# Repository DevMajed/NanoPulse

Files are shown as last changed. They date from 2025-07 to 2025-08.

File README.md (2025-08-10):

# NanoPulse – A Precision 24-bit Pulse Capture Digitizer
Hardware project — firmware will live in another repo.

# Purpose & Use Cases
**NanoPulse** is a 2-channel, 24-bit, trigger-synchronized digitizer for **µs-scale pulses**. It gives a cleaner, more deterministic “scope view” with higher vertical resolution, lower drift, and easy automation in a tiny form factor.
- What: 24-bit, 2-channel digitizer for µs pulses (hundreds of kHz BW).  
- For: labs validating pulse shape, battery DCIR, and rail transients, Ultrasonic/sonar echo logger (lab/test-tank, 40–300 kHz)
- Why: cleaner data than 8–12-bit scopes, deterministic trigger, tiny + scriptable.








---

# Purpose & Use Cases

**NanoPulse** delivers a deterministic external-trigger capture path tuned for **hundreds of kHz BW** and **µs pulses**.

## 1) Scope-replacement for pulsed benches (µs pulses)
**What it solves**  
Verify the **actual** applied pulse (rise/fall, overshoot, flatness, droop) without wheeling in a DSO.

**Who it’s for**  
Power-electronics / microwave labs, bench integrators.

**Hook**  
24-bit depth + clean CNV trigger reveals subtle flat-top errors and overshoot that 8–12-bit scopes smear.

**Connect (minimal extras)**
- `Sense Out (BNC/SMA)` → `NanoPulse IN` *(use a simple divider if needed)*
- `External Trigger (DDG/TTL)` → `TRIG IN` *(optional on-board 50 Ω)*

**Quick checklist**
- [ ] Minimal overshoot/ringing  
- [ ] Flat-top ripple/droop within spec  
- [ ] Repeated pulses overlay tightly (deterministic timing)

**Output**  
CSV + plots via simple Python scripts.

---

## 2) Battery / Cell DCIR & Pulsed-Load Logging
**What it solves**  
Clean capture of **voltage droop and relaxation** during programmed load pulses (≈10 µs–100 ms) for DCIR and transient analysis.

**Who it’s for**  
Battery research labs, EV startups, QA.

**Hook**  
High dynamic range + low drift → clearer droop and recovery curves than a typical scope; easy CSV export.

**Connect (minimal extras)**
- `Cell V` → `NanoPulse IN` *(add a 2-resistor divider if V exceeds input range)*  
- Optional: `Shunt V (current)` → `CH2`

**Quick checklist**
- [ ] Stable ΔV (droop) across repeats  
- [ ] Consistent relaxation time constants (τ)  
- [ ] Negligible baseline drift on long captures

**Output**  
CSV of V(t) (and I(t) if used), with auto-computed DCIR and τ.

---

## 3) Power-Rail / Load-Step Transient Verification (PMIC/LDO)
**What it solves**  
Measures **droop, settling time, and small ripple** on precision rails during load steps (≈100 µs–10 ms).

**Who it’s for**  
Analog/PMIC teams, embedded HW labs.

**Hook**  
24-bit vertical resolution + drift stability → see micro-ripple/settling that scopes miss.

**Connect (minimal extras)**
- `Rail` → `NanoPulse IN` *(use a small divider if needed)*  
- `Load-Step Trigger` → `TRIG IN` *(or use Manual Trigger)*

**Quick checklist**
- [ ] Droop within budget  
- [ ] No excessive undershoot/overshoot  
- [ ] Settling to ±x% within target time

**Output**  
CSV + auto-generated plot with annotated droop/settling metrics.

---

## 4) Ultrasonic / Sonar Echo Logging (lab/test-tank, 40–300 kHz)

**What it solves**  
Time-locked recording of **echo waveforms** for TOF, envelope, and multipath analysis—without touching OEM sonar firmware.

**Who it’s for**  
University acoustics/ultrasound labs, NDT benches, AUV/ROV research groups.

**Hook**  
24-bit dynamic range + deterministic trigger resolves **weak echoes** and small envelope changes better than typical 12–16-bit scopes.

**Connect (minimal extras)**
- `Receiver/Baseband Out (BNC/SMA)` → `NanoPulse IN` *(stay within input range or use a simple divider)*  
- `TX Sync/Trigger (TTL)` → `TRIG IN` *(optional on-board 50 Ω)*

**Quick checklist**
- [ ] Stable ping-to-echo timing (TOF) across repeats  
- [ ] Envelope + multipath clearly visible in the 40–300 kHz band  
- [ ] No clipping; baseline drift negligible on long logs

**Output**  
CSV of echo segments + optional envelope/spectrogram plots via Python.

---

# Headline Specs
- **ADC:** Analog Devices **AD4630-24**, up to **2 MSPS**, 24-bit  
- **Channels:** 2 differential, fully-differential amp (FDA) driven  
- **Trigger:** external **TRIG IN** → Schmitt-conditioned → CNV; **Manual Trigger** pad  
- **I/O domains:** **1.8 V** (ADC) and **3.3 V** (MCU) with level translators  
- **Reference:** **LTC6655-5** low-noise, low-drift  
- **Rails:** **LT3042** (+5.4 V), **LT3093** (−5.4 V), **LT1763** (1.8 V & 3.3 V)  
- **Configurable 50 Ω trigger termination** for DDG/coax use (DNP by default)

**Bandwidth envelope (typical build)**
- Usable analog BW: ~**300–600 kHz** (tunable via RCs)
- Practical “clean shape” pulse widths: **≥ 5–10 µs** (2 MSPS sampling)
- **Detect-only minimum pulse:** ~**1–2 µs** (1–2 samples)

---

# Design Highlights (Decisions & Rationale)
- **Anti-alias vs. settling (µs pulses in mind):** modest input Rs (~54 Ω) and small caps (≈1–2.7 nF) around the FDA target a **few-hundred-kHz to ~1 MHz** shaping—enough to see µs edges while improving settling and noise.
- **Low-drift reference path:** **LTC6655-5** with **10 µF + 0.1 µF** close to ADC REF minimizes baseline wander in long captures.
- **Trigger integrity:** External TRIG goes through a **Schmitt buffer + enable/OR logic** to produce a crisp **CNV**; **50 Ω** termination is **optional** for DDG/coax use.
- **Signal integrity at the converter:** **33 Ω series** per ADC input leg for damping; **22–33 Ω** on **CNV** after level translation to tame edges.
- **Clean domain split:** Translators isolate the quiet **1.8 V ADC** domain from **3.3 V MCU**, enabling fast SPI and **BUSY** handshaking.

---

## Trigger Modes
- **External-coax (DDG):** populate 50 Ω at TRIG IN; QC/DDG drives a matched line.  
- **Local-logic:** leave 50 Ω DNP; CNV is driven via translator with a **22–33 Ω** series resistor.

---

## Bring-Up Checklist
- **Power-only:** verify +5.4 V, −5.4 V, +3.3 V, +1.8 V rails; REF ≈ 5.000 V.  
- **CNV source:** confirm 3.3 V at Schmitt output and **1.8 V** at ADC CNV.  
- **Zero-volt short noise:** short IN+ to IN− at SMA; log RMS code spread.  
- **Step/edge:** feed a known step; confirm minimal ringing and proper settling.  
- **Drift:** shorted input, log ≥1 h; expect very low baseline drift.

---

## Safety & Limits
- Keep inputs **within safe range** (use passive dividers when needed).  
- Target content **≤ ~1 MHz** and **µs-scale** pulses.  
- For **ns edges/RF**, use a high-BW DSO/GHz digitizer.

---

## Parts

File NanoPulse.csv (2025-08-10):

Reference | Qty | Value | DNP | Exclude from BOM | Exclude from Board | Footprint | Manufacturer | Mfg part # | Digikey
C1,C3,C7,C8,C10,C17,C18,C19,C66,C67,C75,C76 | 12 | 1uF |  |  |  | Capacitor_SMD:C_0603_1608Metric | Samsung Electro-Mechanics | CL10B105KP8NNNC | 1276-1946-1-ND
C2,C4,C16 | 3 | 47uF 25V 1206 |  |  |  | Capacitor_SMD:C_1206_3216Metric | Cal-Chip Electronics, Inc. | GMC31X5R476M25NT | 4713-GMC31X5R476M25NTCT-ND
C5,C6,C14,C43,C44,C45,C46,C51,C52,C53,C54,C59,C60,C68,C69 | 15 | 0.01uF 0603 |  |  |  | Capacitor_SMD:C_0603_1608Metric | KEMET | C0603C103J5REC7411 | 399-17568-1-ND
C9,C41,C47,C48,C55,C56 | 6 | 10uF 25V 1206 |  |  |  | Capacitor_SMD:C_1206_3216Metric | Samsung Electro-Mechanics | CL31A106MAHNNNE | 1276-1181-1-ND
C11,C13 | 2 | 100uF |  |  |  | Capacitor_Tantalum_SMD:CP_EIA-3528-21_Kemet-B | KYOCERA AVX | TPSB107K006R0400 | 478-4976-1-ND - Cut Tape
C12,C15,C23,C26,C27 | 5 | 4.7uF |  |  |  | Capacitor_SMD:C_0805_2012Metric | Samsung Electro-Mechanics | CL21A475KAQNNNE | 1276-1244-1-ND
C20,C21 | 2 | 10uF 1206 |  |  |  | Capacitor_SMD:C_1206_3216Metric | Samsung Electro-Mechanics | CL31A106MAHNNNE | 1276-1181-1-ND
C22 | 1 | 0.47uF |  |  |  | Capacitor_SMD:C_0805_2012Metric | Samsung Electro-Mechanics | CL21B474KAFNNNG | 1276-6480-1-ND
C24 | 1 | 47uF 1206 |  |  |  | Capacitor_SMD:C_1206_3216Metric | Cal-Chip Electronics, Inc. | GMC31X5R476M25NT | 4713-GMC31X5R476M25NTCT-ND
C25,C28,C29,C30,C31,C32,C33,C34,C35,C36,C37,C38,C39,C40,C42,C61,C70,C77,C78,C79,C80,C81,C82,C83,C84,C85 | 26 | 0.1uF |  |  |  | Capacitor_SMD:C_0603_1608Metric | YAGEO | CC0603KRX7R7BB104 | 311-1088-1-ND
C49,C50,C57,C58,C64,C65,C73,C74 | 8 | 1000pF |  |  |  | Capacitor_SMD:C_0603_1608Metric | Samsung Electro-Mechanics | CL10B102KB8NNNC | 1276-1018-1-ND
C62,C63,C71,C72 | 4 | 2700pF |  |  |  | Capacitor_SMD:C_0805_2012Metric | Samsung Electro-Mechanics | CL21B272KBANNNC | 1276-2495-1-ND
D1,D2,D3,D4,D10 | 5 | ESD9B5.0ST5G |  |  |  | Diode_SMD:D_SOD-923 |  | ESD9B5.0ST5G | ESD9B5.0ST5GOSCT-ND - Cut Tape
D5,D6,D8,D9,D11,D12 | 6 | Green |  |  |  | LED_SMD:LED_0603_1608Metric | Lite-On Inc. | LTST-C191KGKT | 160-1446-1-ND
D7 | 1 | ESD9B3.3ST5G |  |  |  | Diode_SMD:D_SOD-923 |  | ESD9B3.3ST5G | ESD9B3.3ST5GOSCT-ND
D13 | 1 | LED_RGB |  |  |  | Majed-footprints:APHF1608SEEQBDZGKC_KNB-L | Kingbright | APHF1608SEEQBDZGKC | 754-2144-2-ND
FB1,FB2,FB3,FB4,FB5,FB6,FB7,FB8,FB9,FB10,FB11,FB12,FB13,FB14,FB15 | 15 | 33R |  |  |  | Inductor_SMD:L_0603_1608Metric_Pad1.05x0.95mm_HandSolder | Murata Electronics | BLM18PG330SN1D | 490-5220-1-ND
H1,H2,H3,H4 | 4 | NPTH_PAD |  | Excluded from BOM |  | Mounting_Wuerth:Mounting_Wuerth_WA-SMSI-M1.6_H3.5mm_ThreadDepth2mm_NoNPTH_97730356330
J1,J2,J3,J4,J5 | 5 | SMA_conn |  |  |  | Connector_Coaxial:SMA_Amphenol_132289_EdgeMount | Amphenol RF | 132289RP | ACX1427-ND
J6 | 1 | Conn_01x03_Pin |  |  |  | Connector_Phoenix_MC:PhoenixContact_MC_1,5_3-G-3.5_1x03_P3.50mm_Horizontal | Sullins Connector Solutions | PRPC003SAAN-RC | S1011EC-03-ND
J7 | 1 | STM32 PROGRAMER |  |  |  | Majed-footprints:SPARKFUN_PRT-14417 | SparkFun Electronics | 14417 | 1568-14417-ND
J8 | 1 | USB_B_Micro |  |  |  | Connector_USB:USB_Micro-B_Molex-105017-0001 | Molex | 0473461001 | WM11228CT-ND
Logo1 | 1 | Majed's Logo |  | Excluded from BOM |  | Majed-footprints:Logo_Majed | N-Well Labs
Q1 | 1 | 2N7002K |  |  |  | Package_TO_SOT_SMD:SOT-23 | onsemi | 2N7002LT1G | 2N7002LT1GOSCT-ND
R1,R2,R7,R8 | 4 | 50 |  |  |  | Resistor_SMD:R_0603_1608Metric | YAGEO | RT0603BRE0750RL | 13-RT0603BRE0750RLCT-ND
R3,R4,R5,R6,R35,R44,R45,R54,R55,R56,R57,R66,R67 | 13 | DNI |  |  |  | Resistor_SMD:R_0603_1608Metric
R9,R18,R21,R22 | 4 | 330R |  |  |  | Resistor_SMD:R_0603_1608Metric | TE Connectivity Passive Product | CRGP0603F330R | A130410CT-ND
R10 | 1 | 140R |  |  |  | Resistor_SMD:R_0603_1608Metric | Panasonic Electronic Components | ERJ-3EKF1400V | P140HCT-ND
R11 | 1 | 47.5K |  |  |  | Resistor_SMD:R_0603_1608Metric | YAGEO | RC0603FR-071KL | 311-47.5KHRCT-ND
R12,R14,R15,R26,R29,R30,R31,R32,R46,R48,R58,R60 | 12 | 10K |  |  |  | Resistor_SMD:R_0603_1608Metric | YAGEO | RC0603FR-0710KL | 311-10.0KHRCT-ND
R13 | 1 | 16.9K |  |  |  | Resistor_SMD:R_0603_1608Metric | Stackpole Electronics Inc | RMCF0603FT16K9 | RMCF0603FT16K9CT-ND
R16 | 1 | 54.2K |  |  |  | Resistor_SMD:R_0603_1608Metric | KOA Speer Electronics, Inc. | RN73H1JTTD5422B25 | 2019-RN73H1JTTD5422B25CT-ND
R17 | 1 | 3.3K |  |  |  | Resistor_SMD:R_0603_1608Metric | YAGEO | RC0603FR-073K3L | 311-3.30KHRCT-ND
R19 | 1 | 54.9R |  |  |  | Resistor_SMD:R_0603_1608Metric | YAGEO | RC0603FR-0754R9L | 311-54.9HRCT-ND
R20 | 1 | 49.9K |  |  |  | Resistor_SMD:R_0603_1608Metric | YAGEO | RC0603FR-0756KL | 311-56KHRCT-ND
R23,R24 | 2 | 400 |  |  |  | Resistor_SMD:R_0603_1608Metric | Vishay Dale Thin Film | PAT0603E4000BST1 | PAT400ACT-ND
R25 | 1 | 825 |  |  |  | Resistor_SMD:R_0603_1608Metric | YAGEO | RC0603FR-07825RL | 311-825HRCT-ND
R27 | 1 | 100 |  |  |  | Resistor_SMD:R_0603_1608Metric | RC0603FR-07100RL | RC0603FR-07100RL | 311-100HRCT-ND
R28 | 1 | 20K |  |  |  | Resistor_SMD:R_0603_1608Metric | YAGEO | RC0603FR-0720KL | 311-20.0KHRCT-ND
R33 | 1 | 100K |  |  |  | Resistor_SMD:R_0603_1608Metric | YAGEO | RC0603FR-07100KL | 311-100KHRCT-ND
R34 | 1 | 0 |  |  |  | Resistor_SMD:R_0603_1608Metric | YAGEO | RC0603JR-070RL | 311-0.0GRCT-ND
R36,R37,R40,R41 | 4 | 10 |  |  |  | Resistor_SMD:R_0805_2012Metric | YAGEO | RC0805FR-0710RL | 311-10.0CRCT-ND
R38,R39,R42,R43,R68,R69,R70 | 7 | 33 |  |  |  | Resistor_SMD:R_0603_1608Metric | YAGEO | RC0603FR-072KL | 311-33GRCT-ND
R47,R49,R59,R61 | 4 | 54.09 |  |  |  | Resistor_SMD:R_0603_1608Metric | YAGEO | RC0603FR-0754R9L | 311-54.9HRCT-ND
R50,R51,R62,R63 | 4 | 1K |  |  |  | Resistor_SMD:R_0603_1608Metric | YAGEO | RC0603FR-071KL | 311-1.00KHRCT-ND
R52,R53,R64,R65 | 4 | 2K |  |  |  | Resistor_SMD:R_0603_1608Metric | YAGEO | RC0603FR-071KL | 311-2.00KHRCT-ND
R71 | 1 | 50 (1210) |  |  |  | Resistor_SMD:R_1210_3225Metric_Pad1.30x2.65mm_HandSolder | Vishay Dale | RCP1206W50R0JTP | 541-RCP1206W50R0JTPCT-ND
R72 | 1 | 500 |  |  |  | Resistor_SMD:R_0603_1608Metric | YAGEO | RT0603BRC07500RL | 13-RT0603BRC07500RLCT-ND
SW1 | 1 | Push - BOOT |  |  |  | Button_Switch_SMD:SW_Tactile_SPST_NO_Straight_CK_PTS636Sx25SMTRLFS | E-Switch | TL59NF160Q | EG2532CT-ND
TP1 | 1 | 5.4V |  |  |  | TestPoint:TestPoint_Pad_1.0x1.0mm
TP2 | 1 | 3.3V |  |  |  | TestPoint:TestPoint_Pad_1.0x1.0mm
TP3 | 1 | -5.4 |  |  |  | TestPoint:TestPoint_Pad_1.0x1.0mm
TP4 | 1 | 1,,8V |  |  |  | TestPoint:TestPoint_Pad_1.0x1.0mm
TP5,TP6 | 2 | 5V |  |  |  | TestPoint:TestPoint_Pad_1.0x1.0mm
TP7 | 1 | UART4_RX |  |  |  | TestPoint:TestPoint_Pad_1.0x1.0mm
TP8 | 1 | UART4_TX |  |  |  | TestPoint:TestPoint_Pad_1.0x1.0mm
TP9 | 1 | UART4_CTS |  |  |  | TestPoint:TestPoint_Pad_1.0x1.0mm
TP10 | 1 | GND |  |  |  | TestPoint:TestPoint_Pad_1.0x1.0mm
TP11 | 1 | SCK |  |  |  | TestPoint:TestPoint_Pad_1.0x1.0mm
TP12 | 1 | BUSY |  |  |  | TestPoint:TestPoint_Pad_1.0x1.0mm
TP13 | 1 | MOSI |  |  |  | TestPoint:TestPoint_Pad_1.0x1.0mm
TP14 | 1 | CNV |  |  |  | TestPoint:TestPoint_Pad_1.0x1.0mm
TP15 | 1 | /CS |  |  |  | TestPoint:TestPoint_Pad_1.0x1.0mm
TP16 | 1 | REF |  |  |  | TestPoint:TestPoint_Pad_1.0x1.0mm
TP17 | 1 | Trig_Detect |  |  |  | TestPoint:TestPoint_Pad_1.0x1.0mm
TP18 | 1 | Trig_Enable |  |  |  | TestPoint:TestPoint_Pad_1.0x1.0mm
TP19 | 1 | Manual_Trigger |  |  |  | TestPoint:TestPoint_Pad_1.0x1.0mm
U1,U2 | 2 | LT1763CS8#PBF |  |  |  | Majed-footprints:SO-8_S_LIT-L | Analog Devices Inc. | LT1763CS8#PBF | 505-LT1763CS8#PBF-ND
U3 | 1 | LT3093IDD-PBF |  |  |  | Majed-footprints:05-08-1725_ADI | Analog Devices Inc. | LT3093IDD#PBF | 505-LT3093IDD#PBF-ND
U4 | 1 | LT1763CS8-1.8-TRPBF |  |  |  | Majed-footprints:SO-8_S_LIT | Analog Devices Inc. | LT1763CS8-1.8#TRPBF | 505-LT1763CS8-1.8#TRPBFCT-ND
U5 | 1 | LTC6655LNBHMS8-5#PBF |  |  |  | Majed-footprints:MSOP-8_MS_LIT-L | Analog Devices Inc. | LTC6655LNBHMS8-5#PBF | 505-LTC6655LNBHMS8-5#PBF-ND
U6 | 1 | LT3042IDD-PBF |  |  |  | Majed-footprints:DFN-10_DD_LIT | Analog Devices Inc. | LT3042IDD#TRPBF | LT3042IDD#TRPBFCT-ND
U7 | 1 | STM32H730VBT6 |  |  |  | Package_QFP:LQFP-100_14x14mm_P0.5mm | STMicroelectronics | STM32H730VBT6 | 497-STM32H730VBT6-ND
U8 | 1 | ESDA6V1BC6 |  |  |  | Package_TO_SOT_SMD:SOT-23-6 | ESDA6V1BC6 | STMicroelectronics | 497-6635-1-ND
U9 | 1 | ECS-1612MV-120-CN-TR |  |  |  | Majed-footprints:ECS-1612MV-120-CN-TR | ECS Inc. | ECS-1612MV-120-CN-TR | XC2833CT-ND
U10 | 1 | AD4630-24 |  |  |  | Majed-footprints:05-08-1797_ADI-L | Analog Devices Inc. | AD4630-24BBCZ-RL | 505-AD4630-24BBCZ-RLCT-ND
U11,U12 | 2 | ADA4896-2ARMZ |  |  |  | Majed-footprints:RM_8_ADI | Analog Devices Inc. | ADA4896-2ARMZ | 505-ADA4896-2ARMZ-ND
U13,U14 | 2 | ADA4945 |  |  |  | Majed-footprints:LFCSP16_ADA4945-1ACPZ-R2_ADI-L | Analog Devices Inc. | ADA4945-1ACPZ-RL | 05-ADA4945-1ACPZ-RLCT-ND
U15,U17 | 2 | FXLH42245MPX |  |  |  | Majed-footprints:MLP24_4P5X3P5_ONS | onsemi | FXLH42245MPX | FXLH42245MPXCT-ND
U16 | 1 | FXL2T245L10X |  |  |  | Majed-footprints:MICROPAK10_2P1X1P6_ONS-L | onsemi | FXL2T245L10X | FXL2T245L10XCT-ND
U18 | 1 | 74LVC2G17GW,125 |  |  |  | Package_TO_SOT_SMD:SOT-363_SC-70-6 | Nexperia USA Inc. | 74LVC2G17GW,125 | 1727-4218-1-ND
U19 | 1 | 74AHC1G08GW,125 |  |  |  | Package_TO_SOT_SMD:SOT-353_SC-70-5 | Nexperia USA Inc. | 74AHC1G08GW,125 | 1727-3148-1-ND
U20 | 1 | 74AHC1G32GW,125 |  |  |  | Package_TO_SOT_SMD:SOT-353_SC-70-5 | Nexperia USA Inc. | 74AHC1G32GW,125 | 1727-3150-1-ND

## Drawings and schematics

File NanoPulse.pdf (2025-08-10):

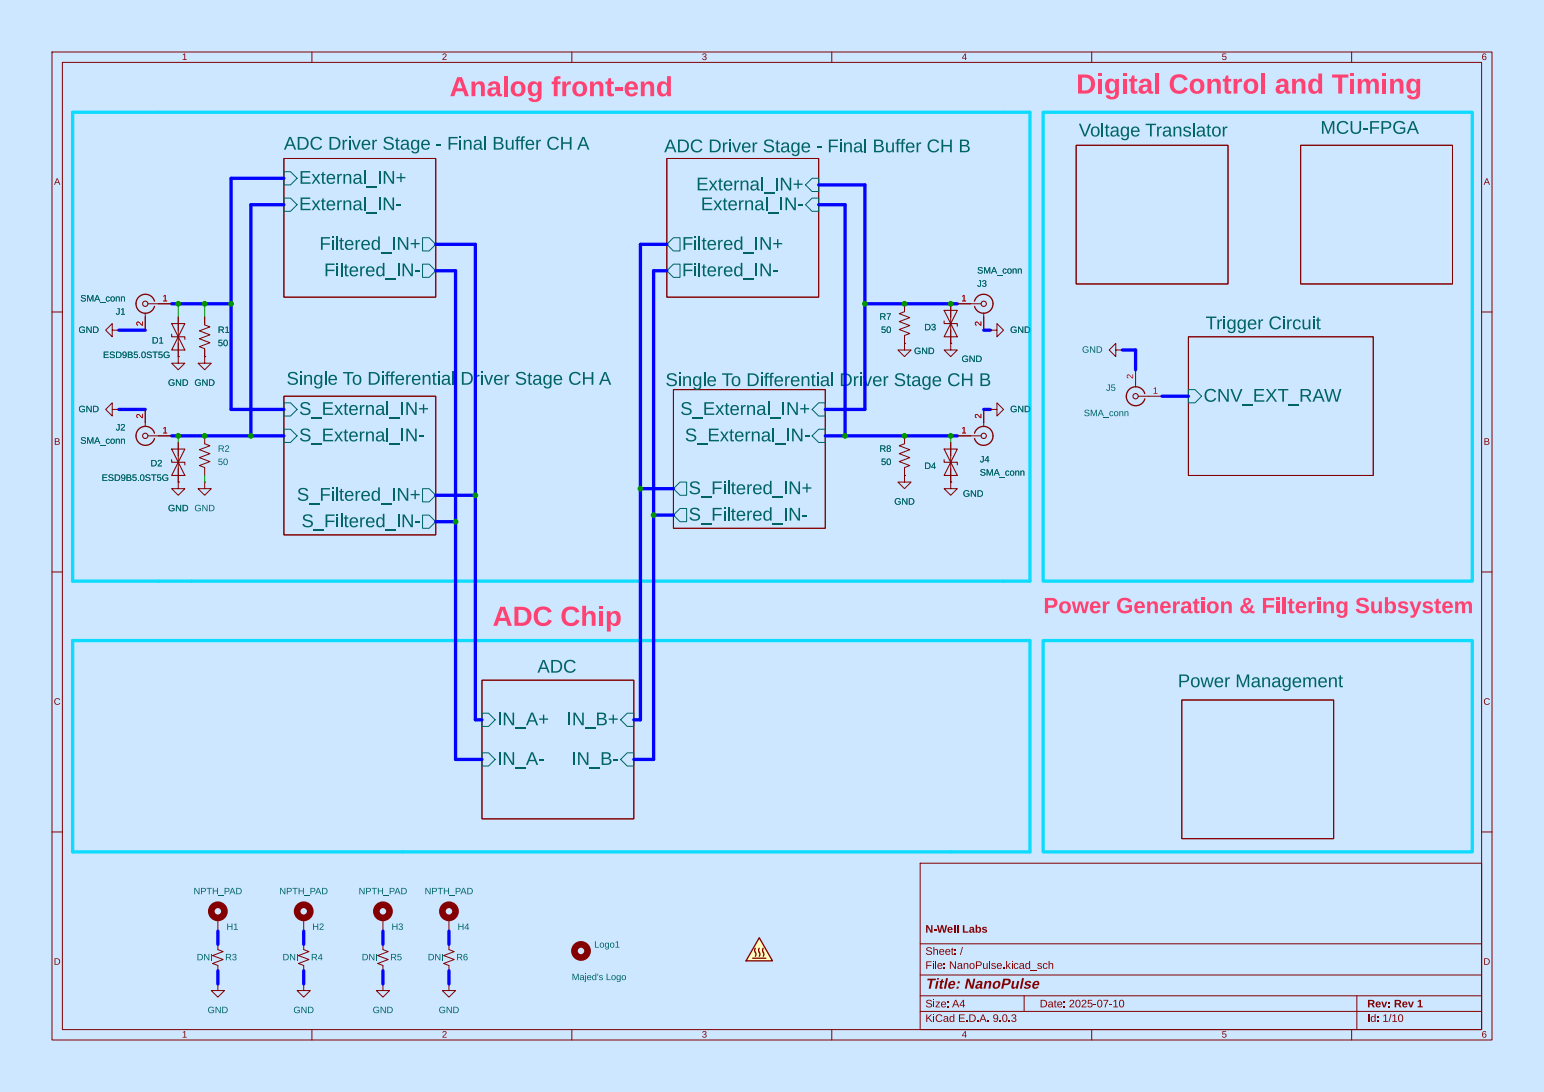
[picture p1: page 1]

Digital Control and Timing

ADC Driver Stage - Final Buffer CH A

ADC Driver Stage - Final Buffer CH B

Single To Differential Driver Stage CH A
S_External_IN+
S_External_IN-

Single To Differential Driver Stage CH B

Power Generation & Filtering Subsystem

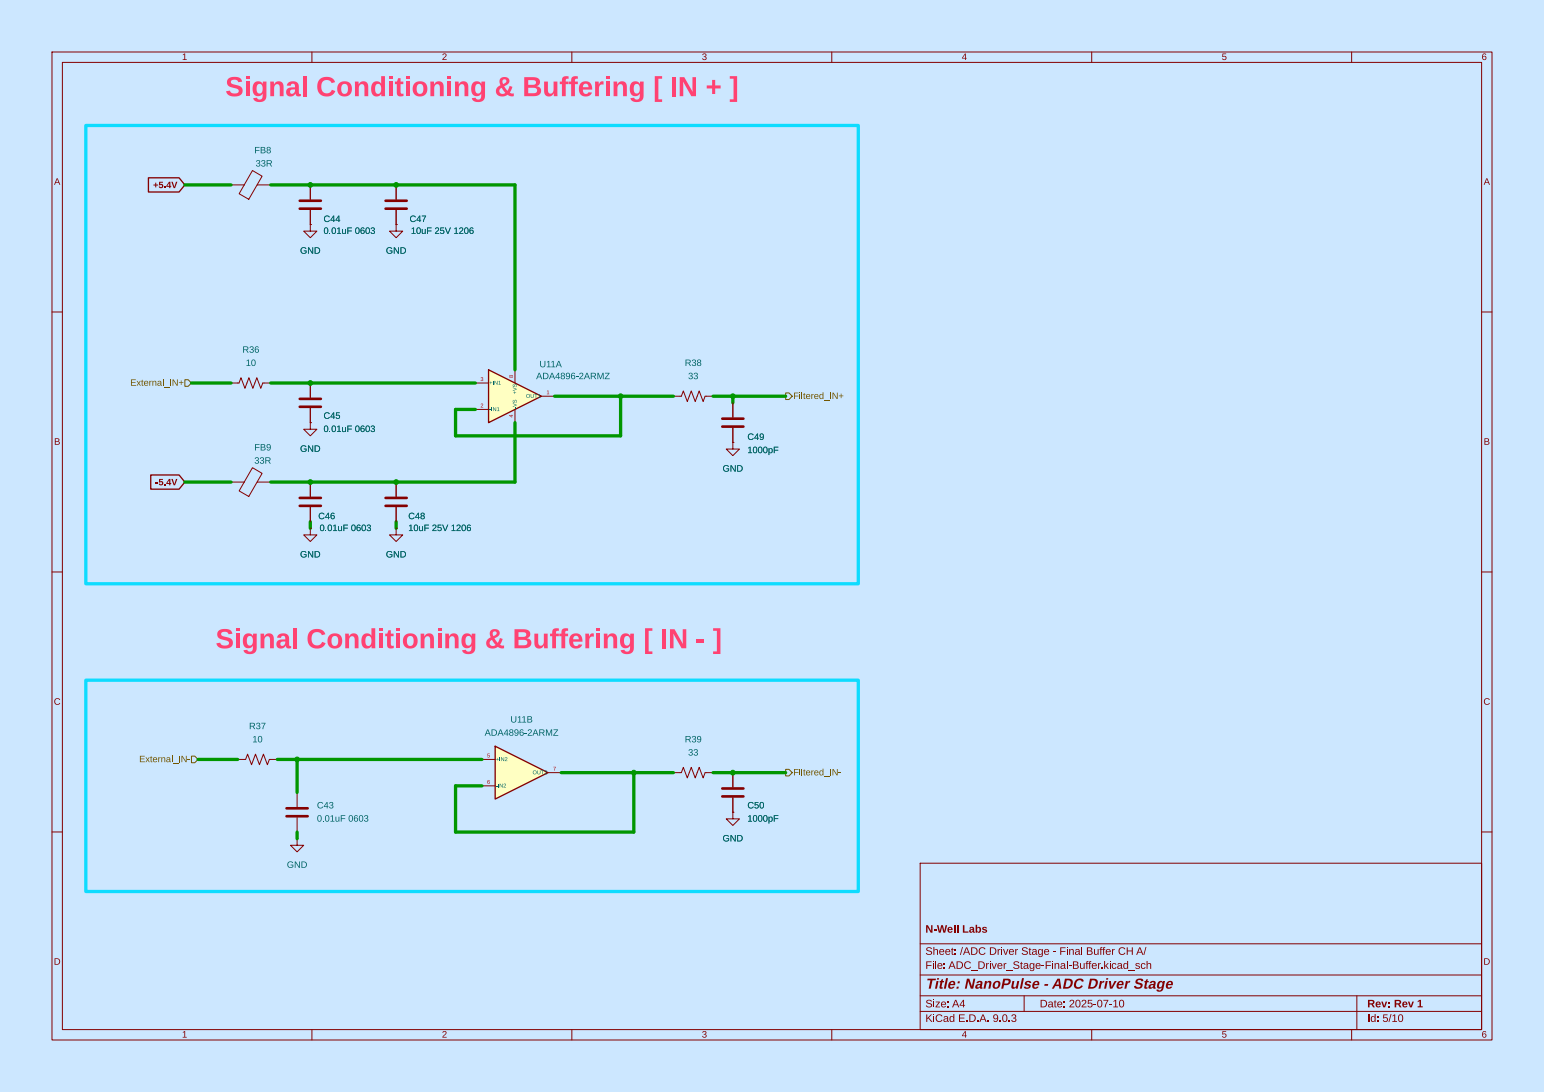
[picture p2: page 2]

Signal Conditioning & Buffering [ IN + ]

File: ADC_Driver_Stage-Final-Buffer.kicad_sch Sheet: /ADC Driver Stage - Final Buffer CH A/ N-Well Labs

Id: 5/10 Title: NanoPulse - ADC Driver Stage

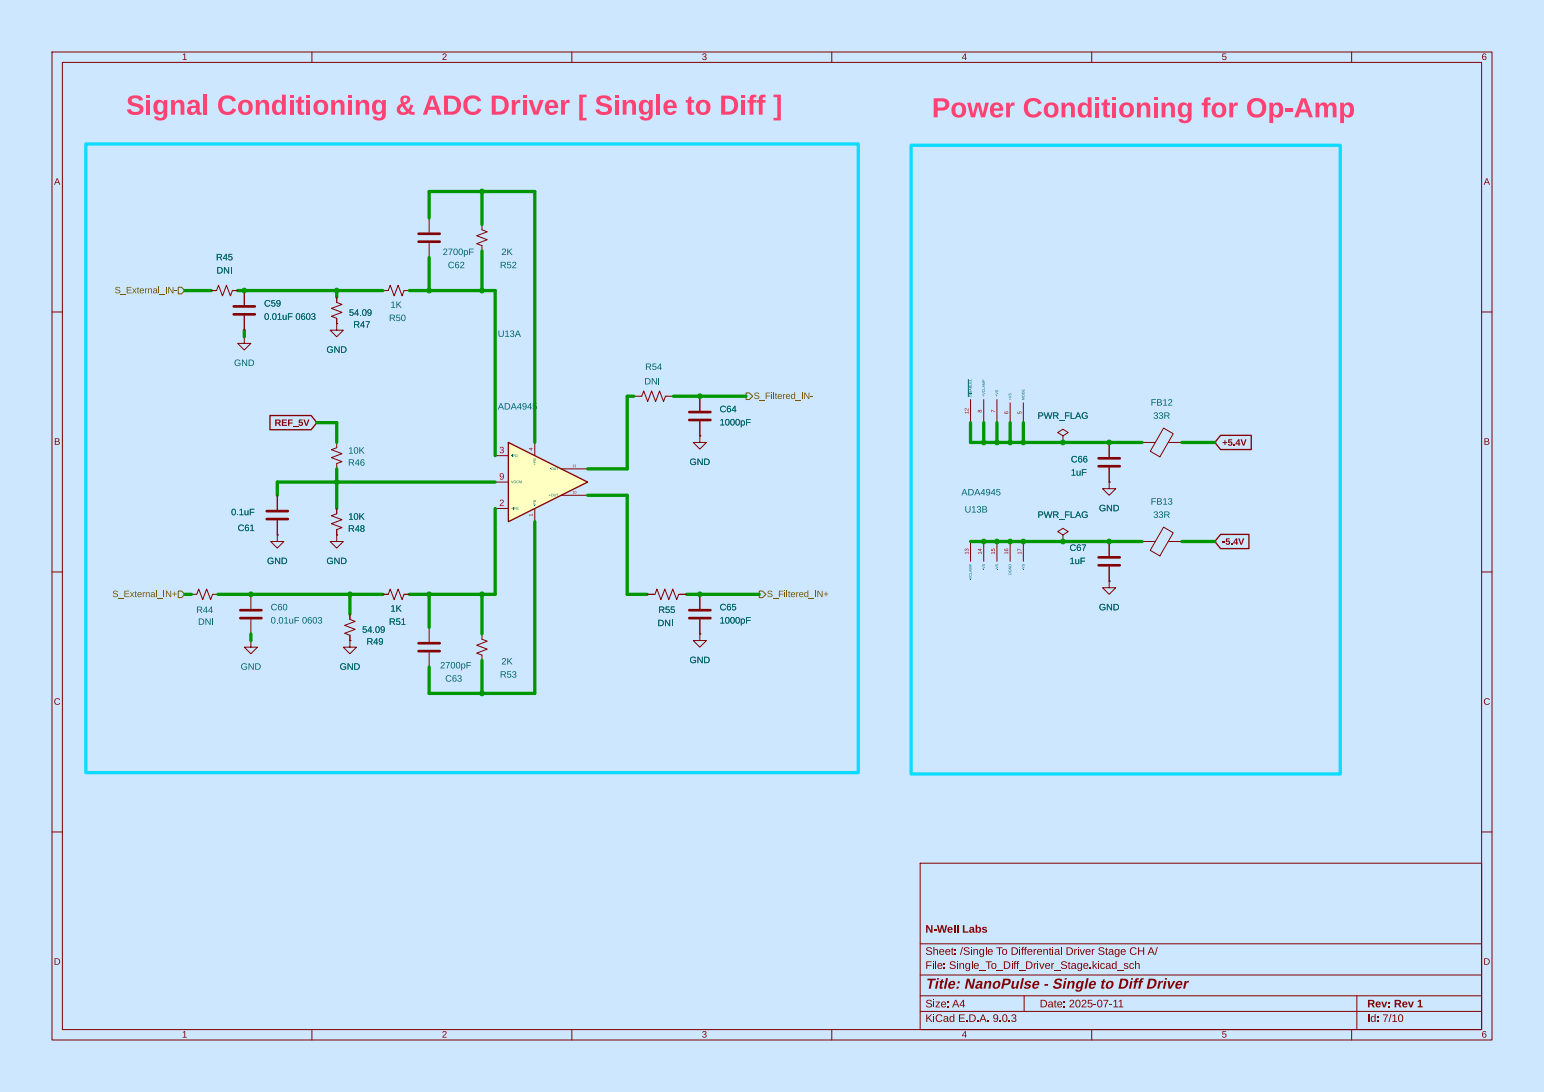
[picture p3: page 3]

Id: 7/10 Title: NanoPulse - Single to Diff Driver File: Single_To_Diff_Driver_Stage.kicad_sch Sheet: /Single To Differential Driver Stage CH A/ N-Well Labs

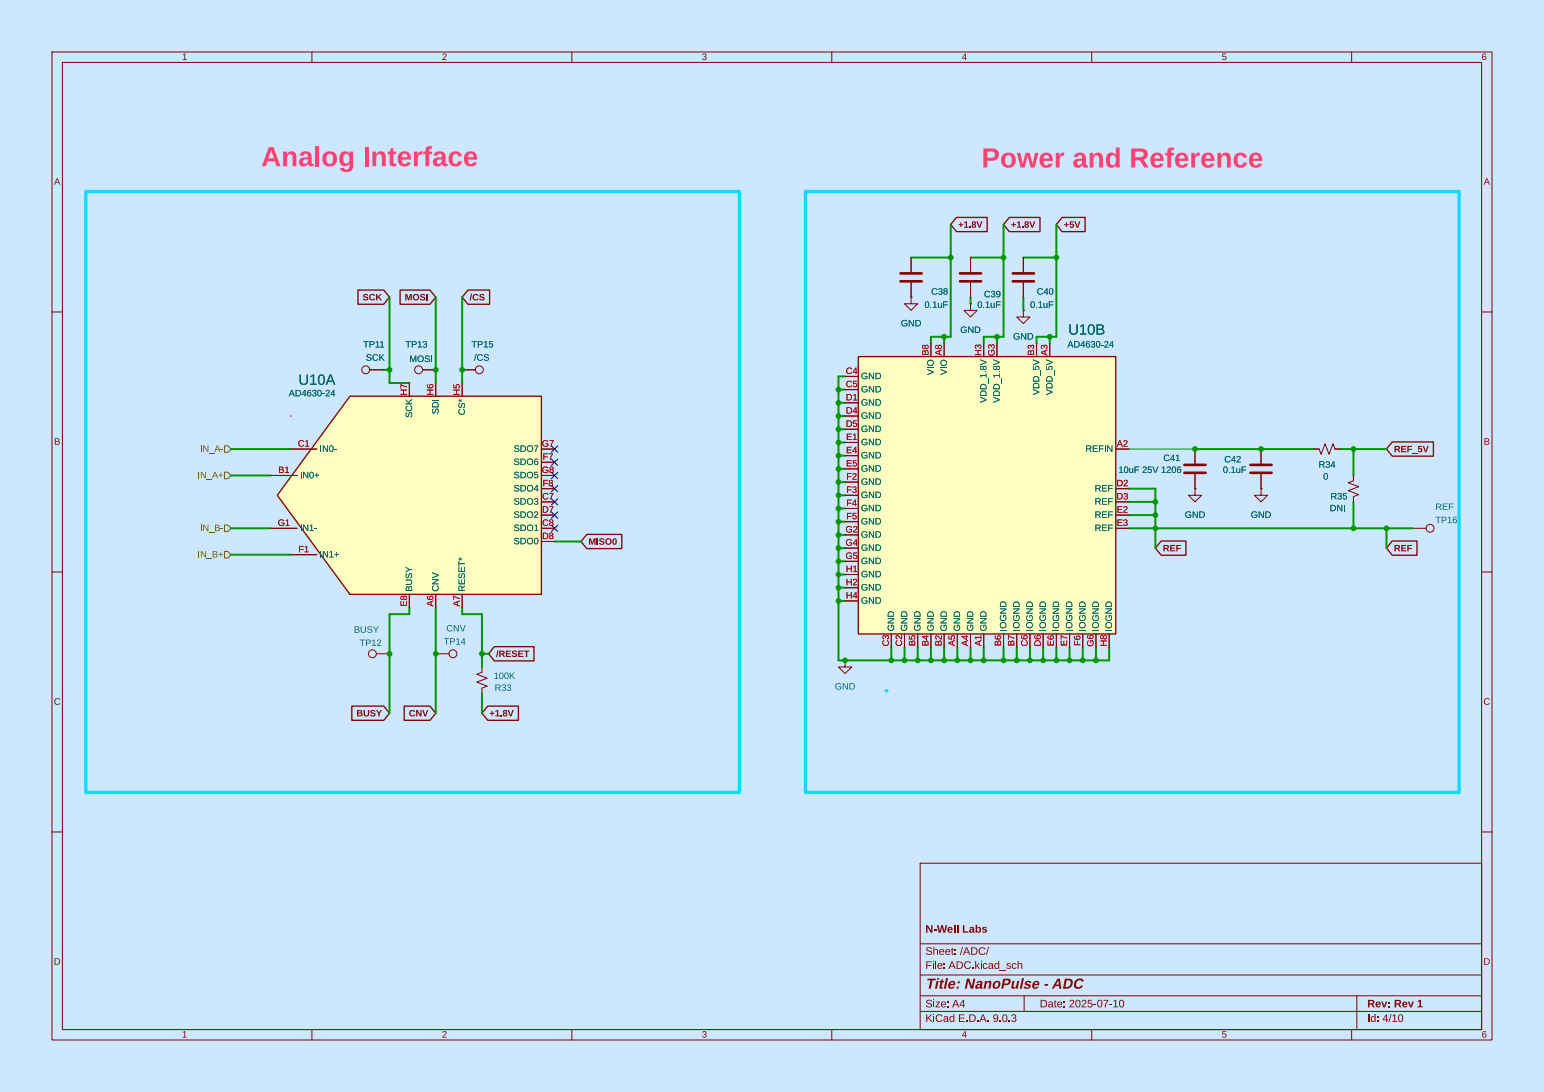
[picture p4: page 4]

SDO7 G7 SDO6 F7 SDO5 G8 SDO4 F8 SDO3 C7 SDO2 D7 SDO1 C8 SDO0 D8 CS* H5 RESET* A7 SDI H6 CNV A6 SCK H7 BUSY E8

File: ADC.kicad_sch Sheet: /ADC/ N-Well Labs

Id: 4/10 Title: NanoPulse - ADC

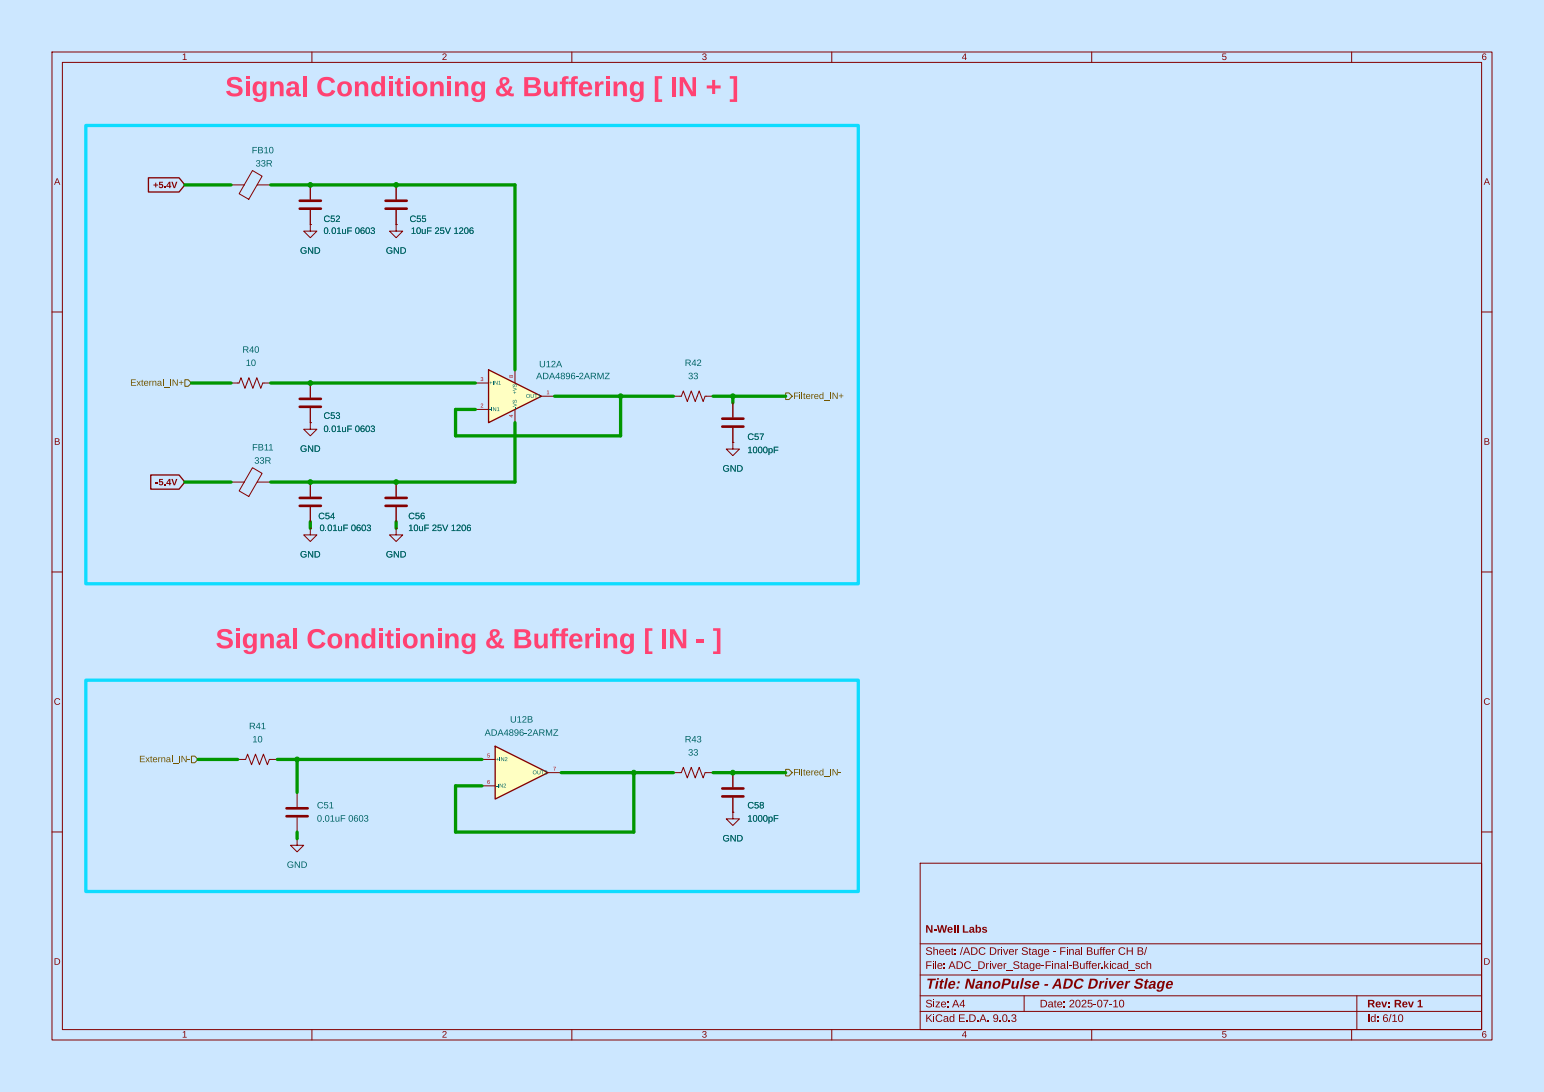
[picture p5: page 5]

Signal Conditioning & Buffering [ IN + ]

File: ADC_Driver_Stage-Final-Buffer.kicad_sch Sheet: /ADC Driver Stage - Final Buffer CH B/ N-Well Labs

Id: 6/10 Title: NanoPulse - ADC Driver Stage

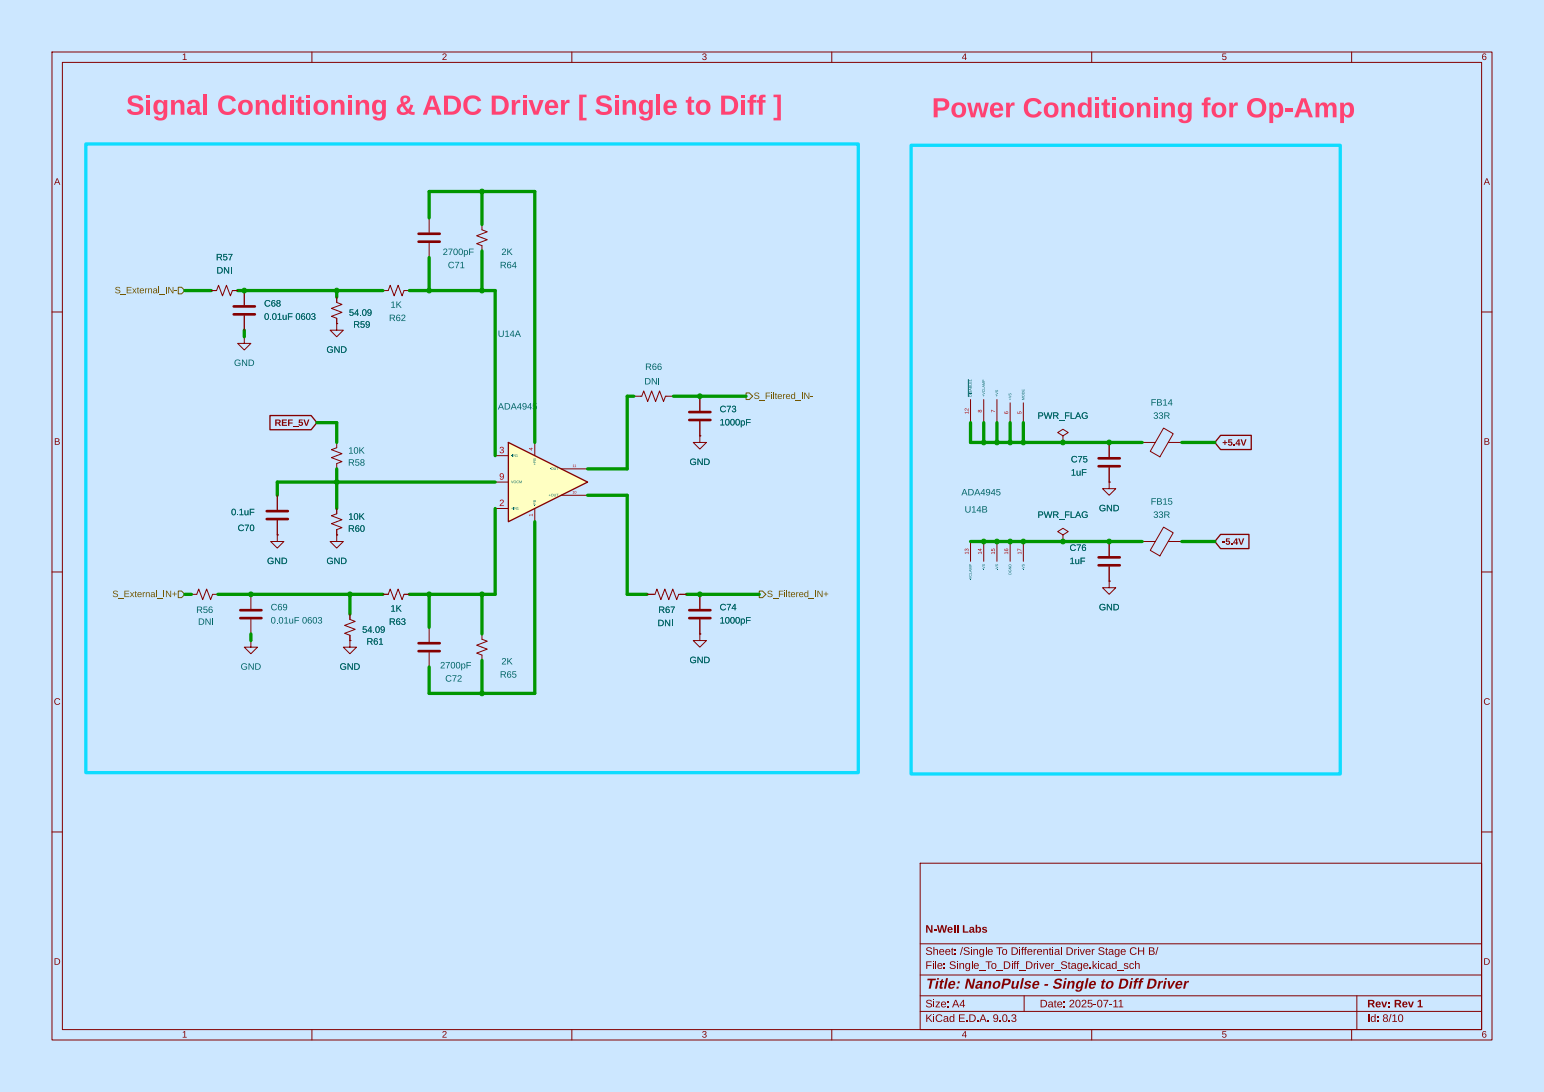
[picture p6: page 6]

1uF -VS 17 MODE 5 DGND 16 +VS 6 -VS 15 +VS 7 -VS 14 +VCLAMP 8 -VCLAMP 13 ~{DISABLE1} 12 U14B
33R GND

Id: 8/10 Title: NanoPulse - Single to Diff Driver File: Single_To_Diff_Driver_Stage.kicad_sch Sheet: /Single To Differential Driver Stage CH B/ N-Well Labs

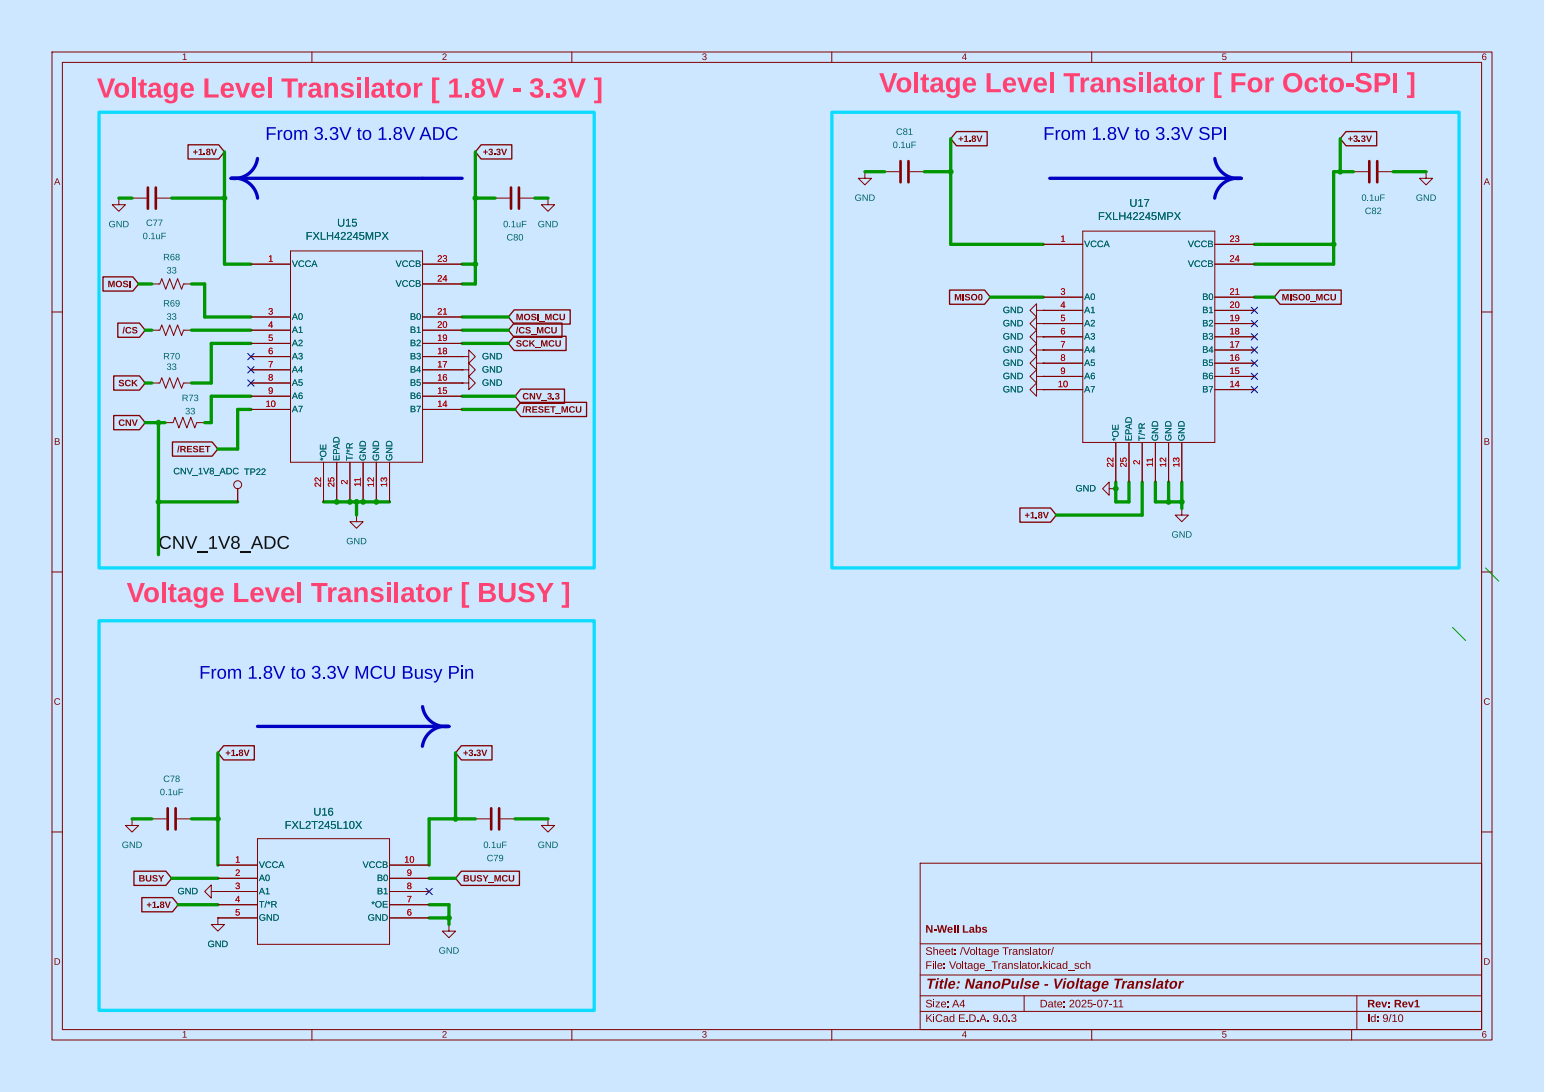
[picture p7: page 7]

2 GND 11 GND 12 GND 13 GND GND GND GND GND GND GND GND GND U15 FXLH42245MPX

Voltage Level Transilator [ BUSY ]

From 1.8V to 3.3V MCU Busy Pin

Id: 9/10 Title: NanoPulse - Violtage Translator File: Voltage_Translator.kicad_sch Sheet: /Voltage Translator/ N-Well Labs

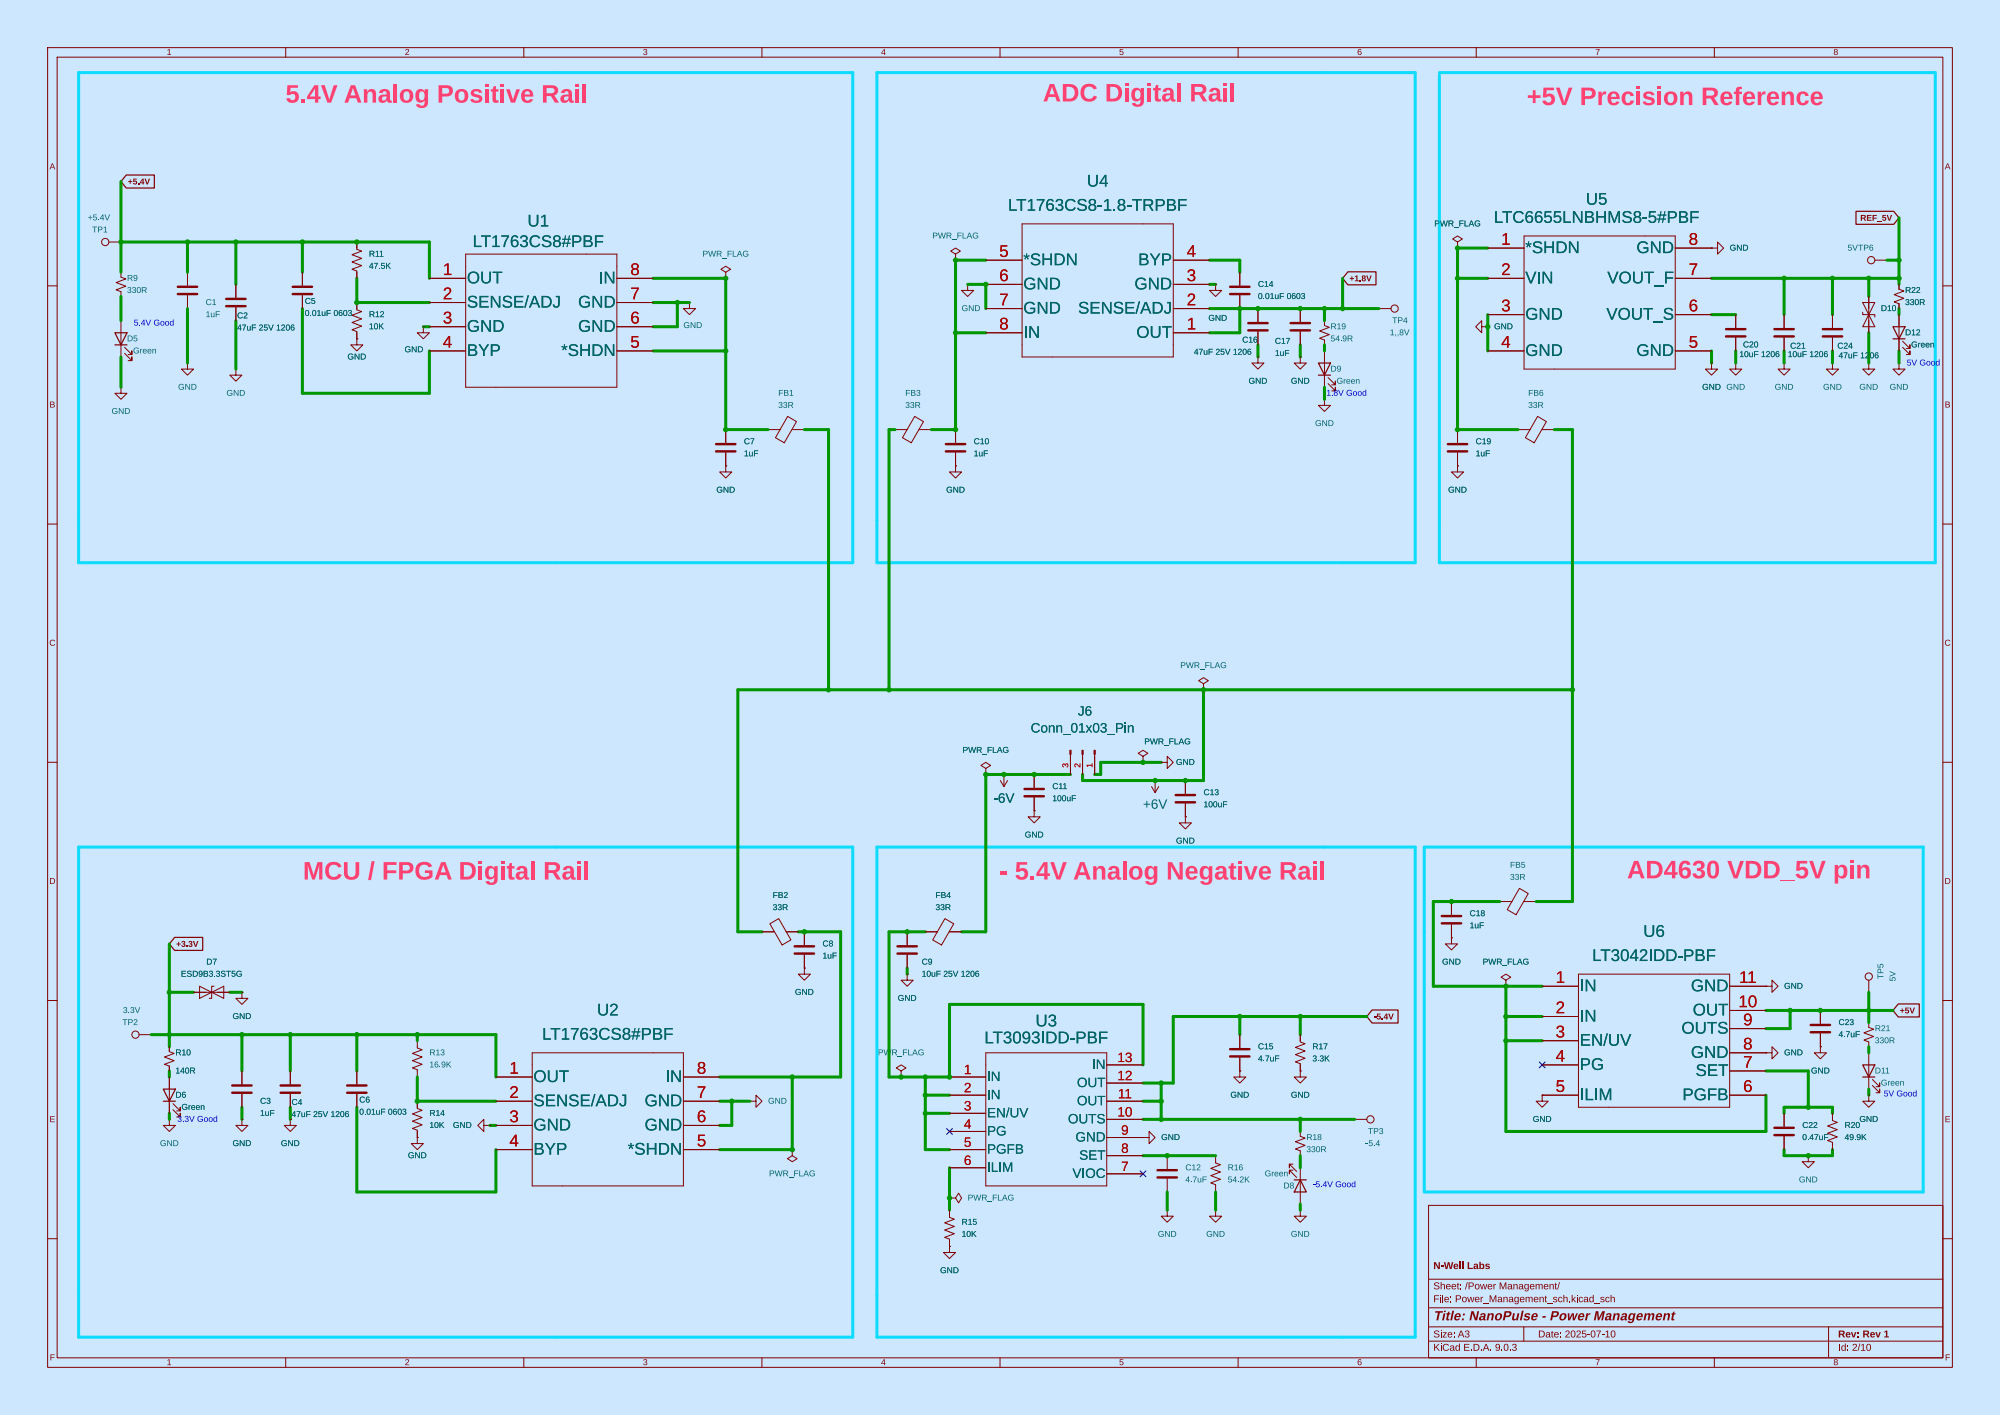
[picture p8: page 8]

5V Good 5.4V Analog Positive Rail

5V Good ADC Digital Rail

MCU / FPGA Digital Rail

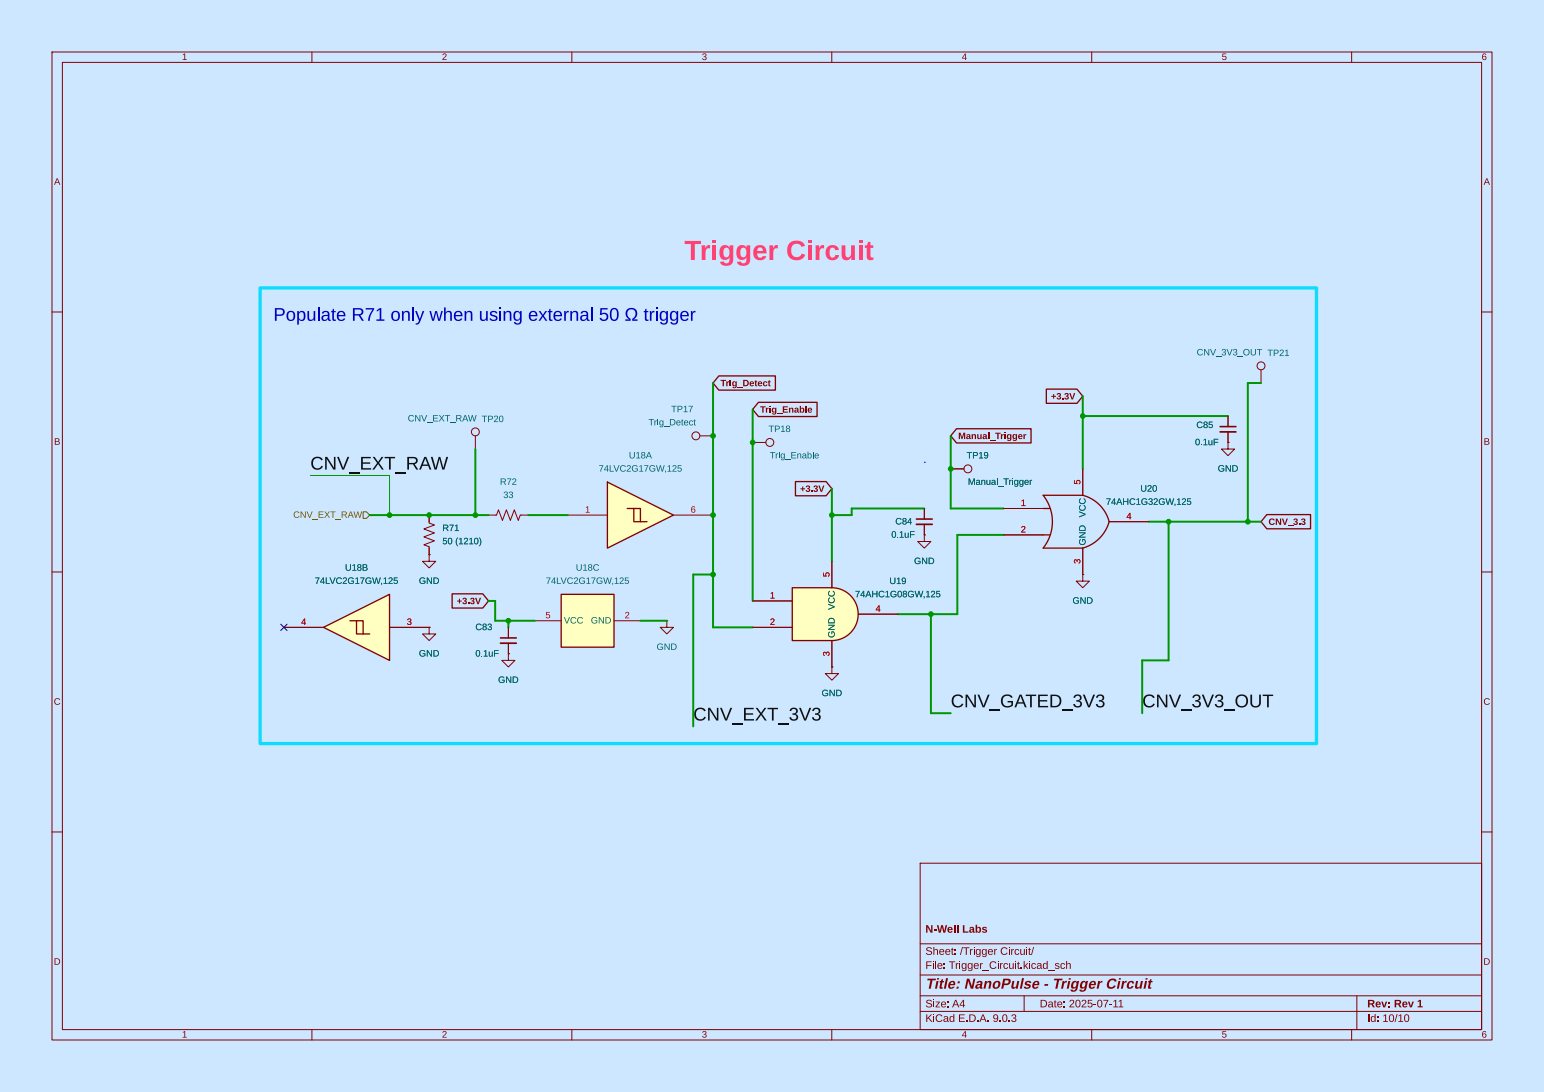
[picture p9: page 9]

Populate R71 only when using external 50 þÿ©trigger R71

Id: 10/10 Title: NanoPulse - Trigger Circuit File: Trigger_Circuit.kicad_sch Sheet: /Trigger Circuit/ N-Well Labs R71
50 (1210) GND

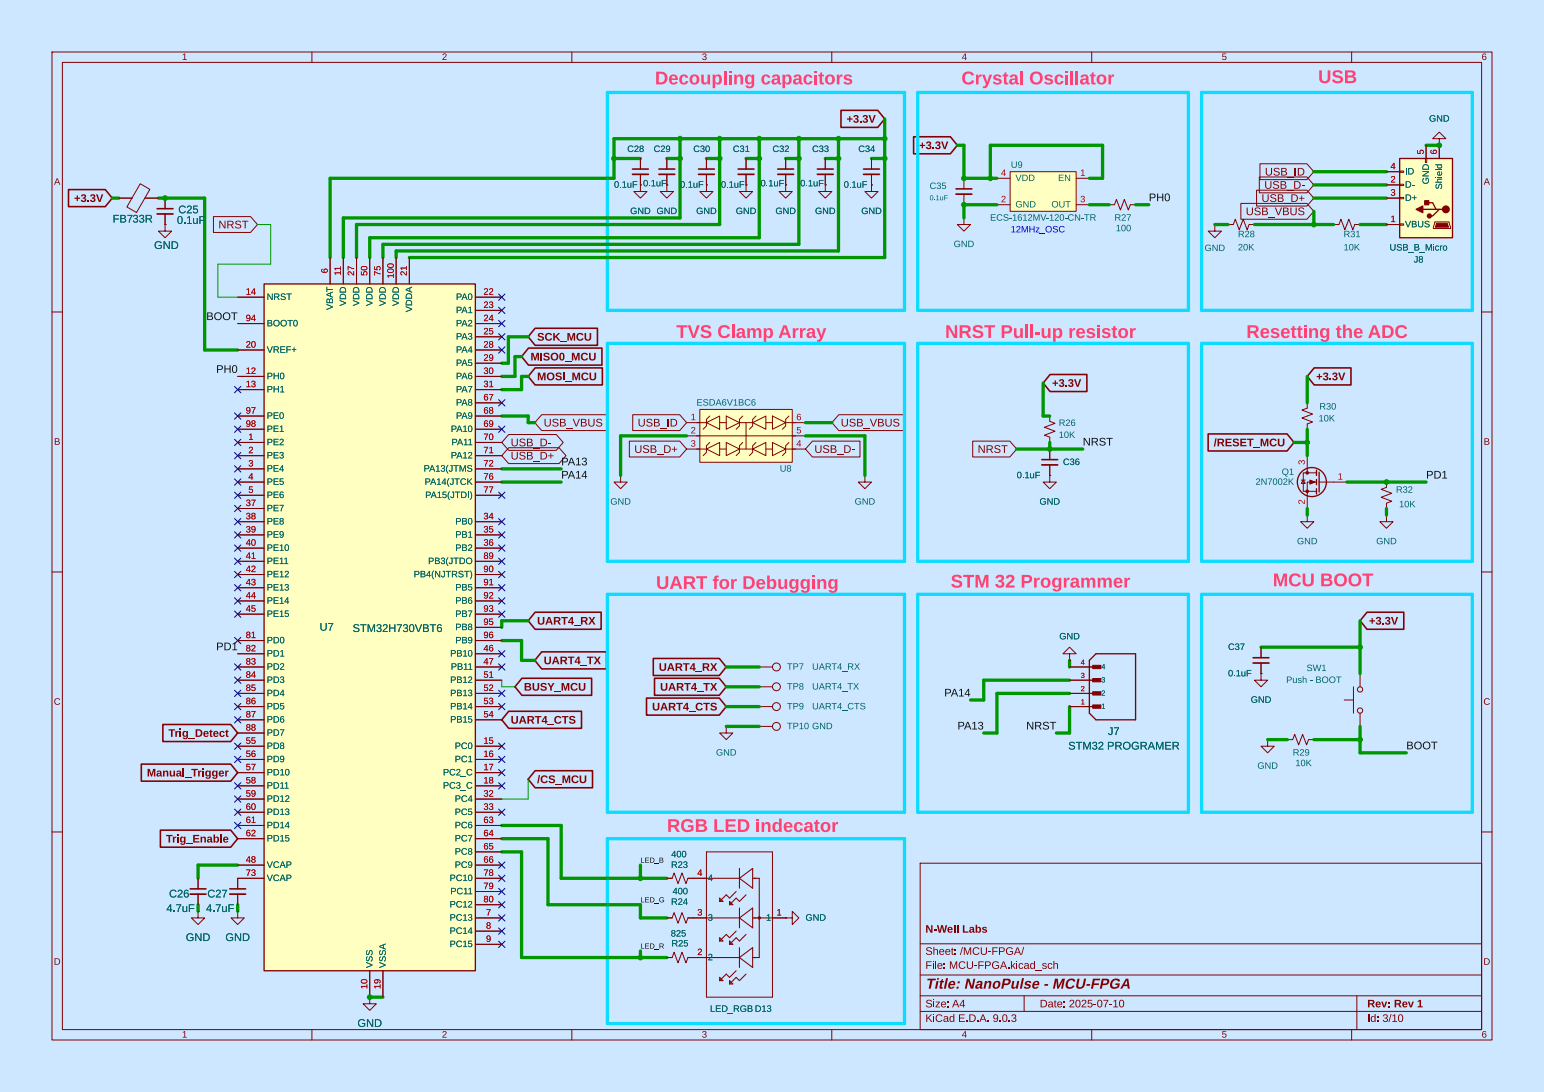
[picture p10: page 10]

6 VDD 11 VDD 27 VDD 50 VSS 10 VDD 75 VSSA 19 VDD 100 VDDA 21 PA0 22 PA1 23 PA2 24 PA3 25 PA4 28 PA5 29 PA6 30 PA7 31 PA8 67 PA9 68 PA10 69 PA11 70 PA12 71 PA13(JTMS 72 PA14(JTCK 76 PA15(JTDI) 77 PB0 34 PB1 35 PB2 36 PB3(JTDO 89 PB4(NJTRST) 90 PB5 91 PB6 92 PB7 93 PB8 95 PB9 96 PB10 46 PB11 47 PB12 51 PB13 52 PB14 53 PB15 54 PC0 15 PC1 16 PC2_C 17 PC3_C 18 PC4 32 PC5 33 PC6 63 PC7 64 PC8 65 PC9 66 PC10 78 PC11 79 PC12 80 PC13 7 PC14 8 PC15 9 C27

6 VDD 11 VDD 27 VDD 50 VSS 10 VDD 75 VSSA 19 VDD 100 VDDA 21 PA0 22 PA1 23 PA2 24 PA3 25 PA4 28 PA5 29 PA6 30 PA7 31 PA8 67 PA9 68 PA10 69 PA11 70 PA12 71 PA13(JTMS 72 PA14(JTCK 76 PA15(JTDI) 77 PB0 34 PB1 35 PB2 36 PB3(JTDO 89 PB4(NJTRST) 90 PB5 91 PB6 92 PB7 93 PB8 95 PB9 96 PB10 46 PB11 47 PB12 51 PB13 52 PB14 53 PB15 54 PC0 15 PC1 16 PC2_C 17 PC3_C 18 PC4 32 PC5 33 PC6 63 PC7 64 PC8 65 PC9 66 PC10 78 PC11 79 PC12 80 PC13 7 PC14 8 PC15 9 U7 STM32H730VBT6

NRST Pull-up resistor

File: MCU-FPGA.kicad_sch Sheet: /MCU-FPGA/ N-Well Labs

Id: 3/10 Title: NanoPulse - MCU-FPGA

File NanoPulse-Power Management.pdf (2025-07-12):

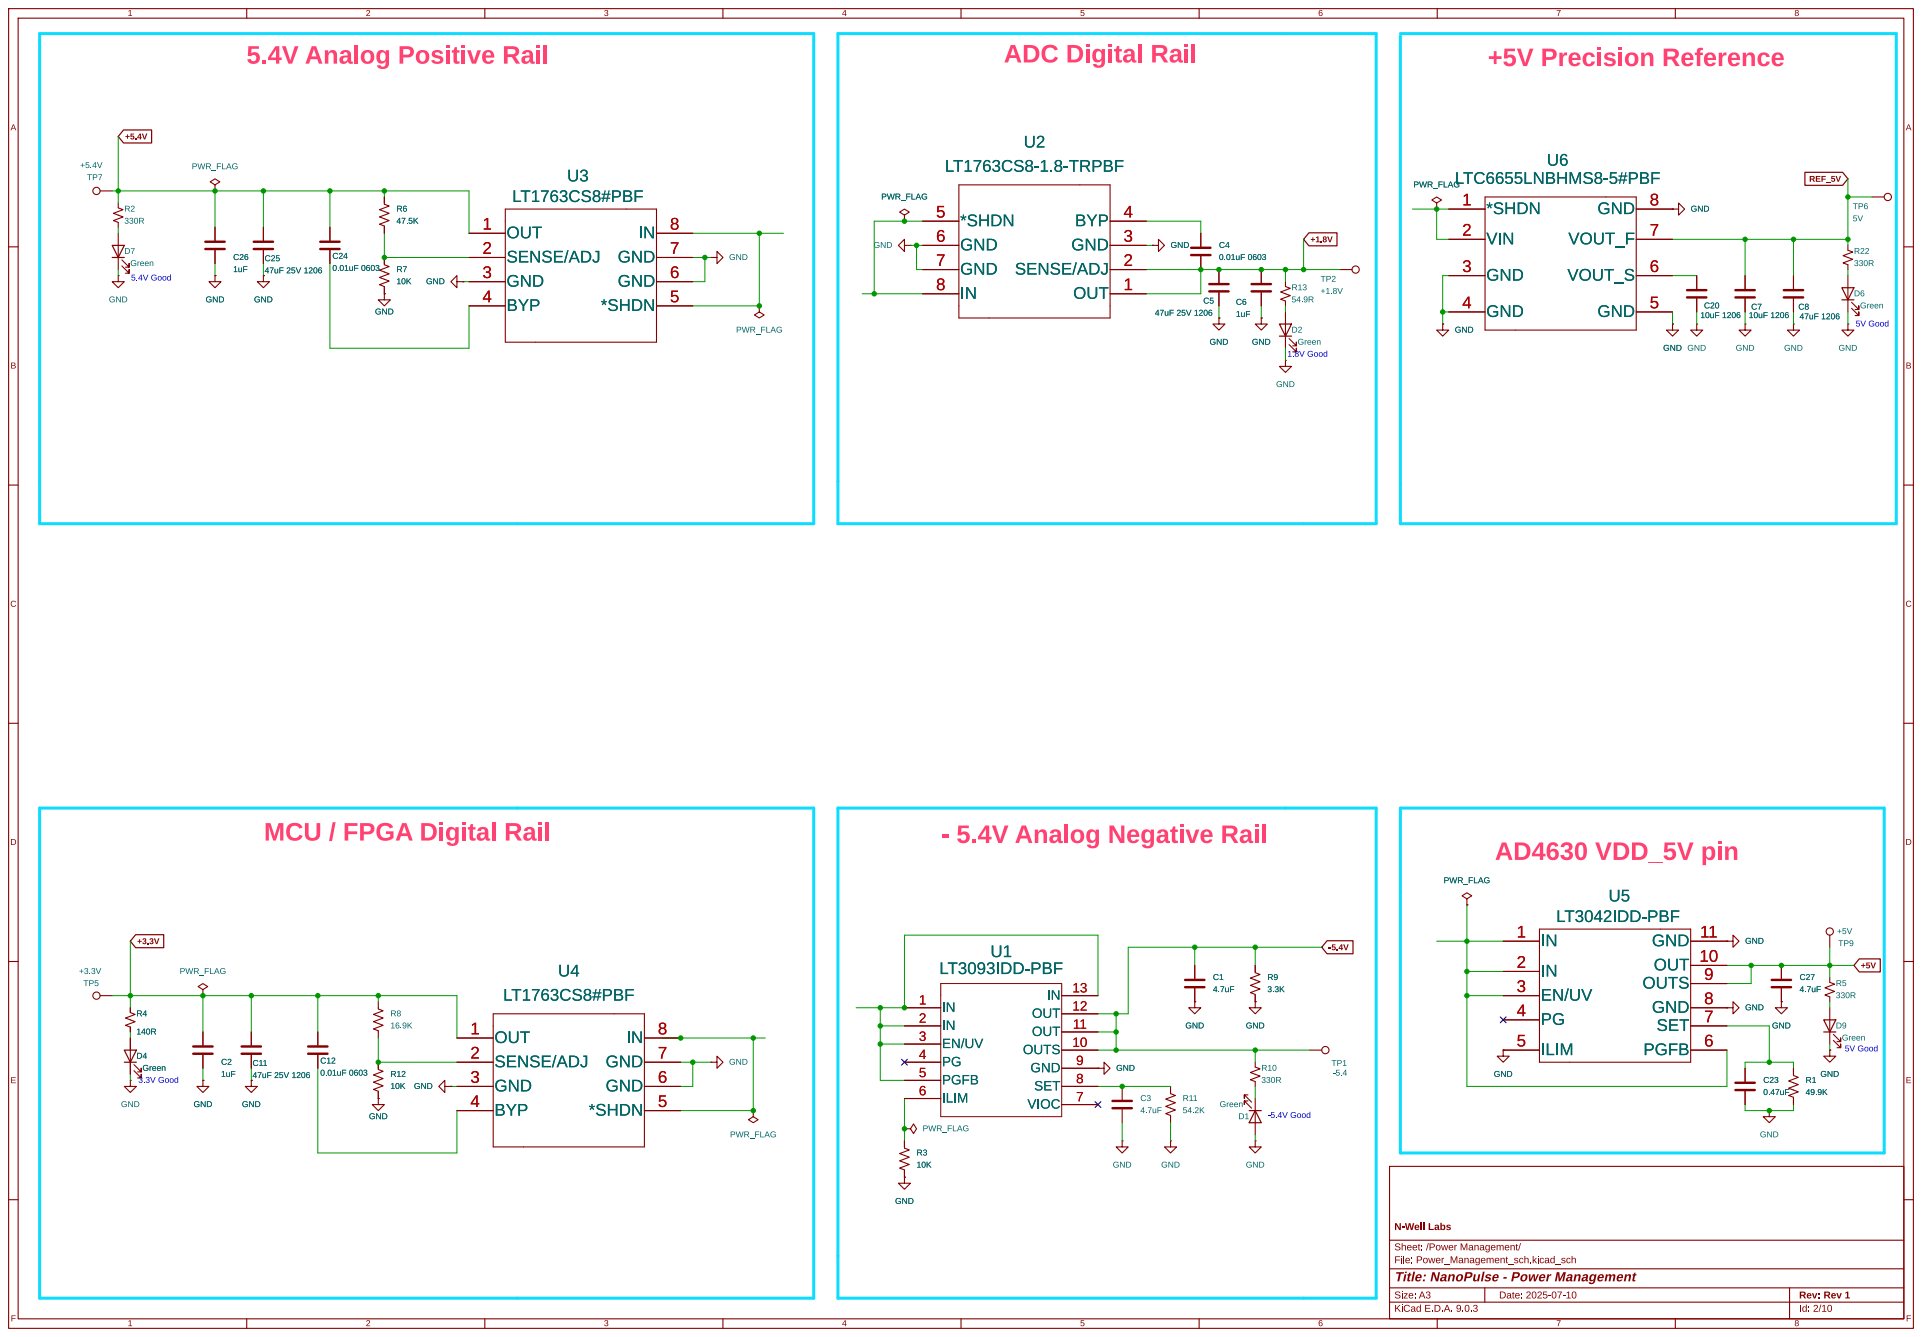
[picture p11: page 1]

5V Good MCU / FPGA Digital Rail

Id: 2/10 Title: NanoPulse - Power Management File: Power_Management_sch.kicad_sch Sheet: /Power Management/ N-Well Labs

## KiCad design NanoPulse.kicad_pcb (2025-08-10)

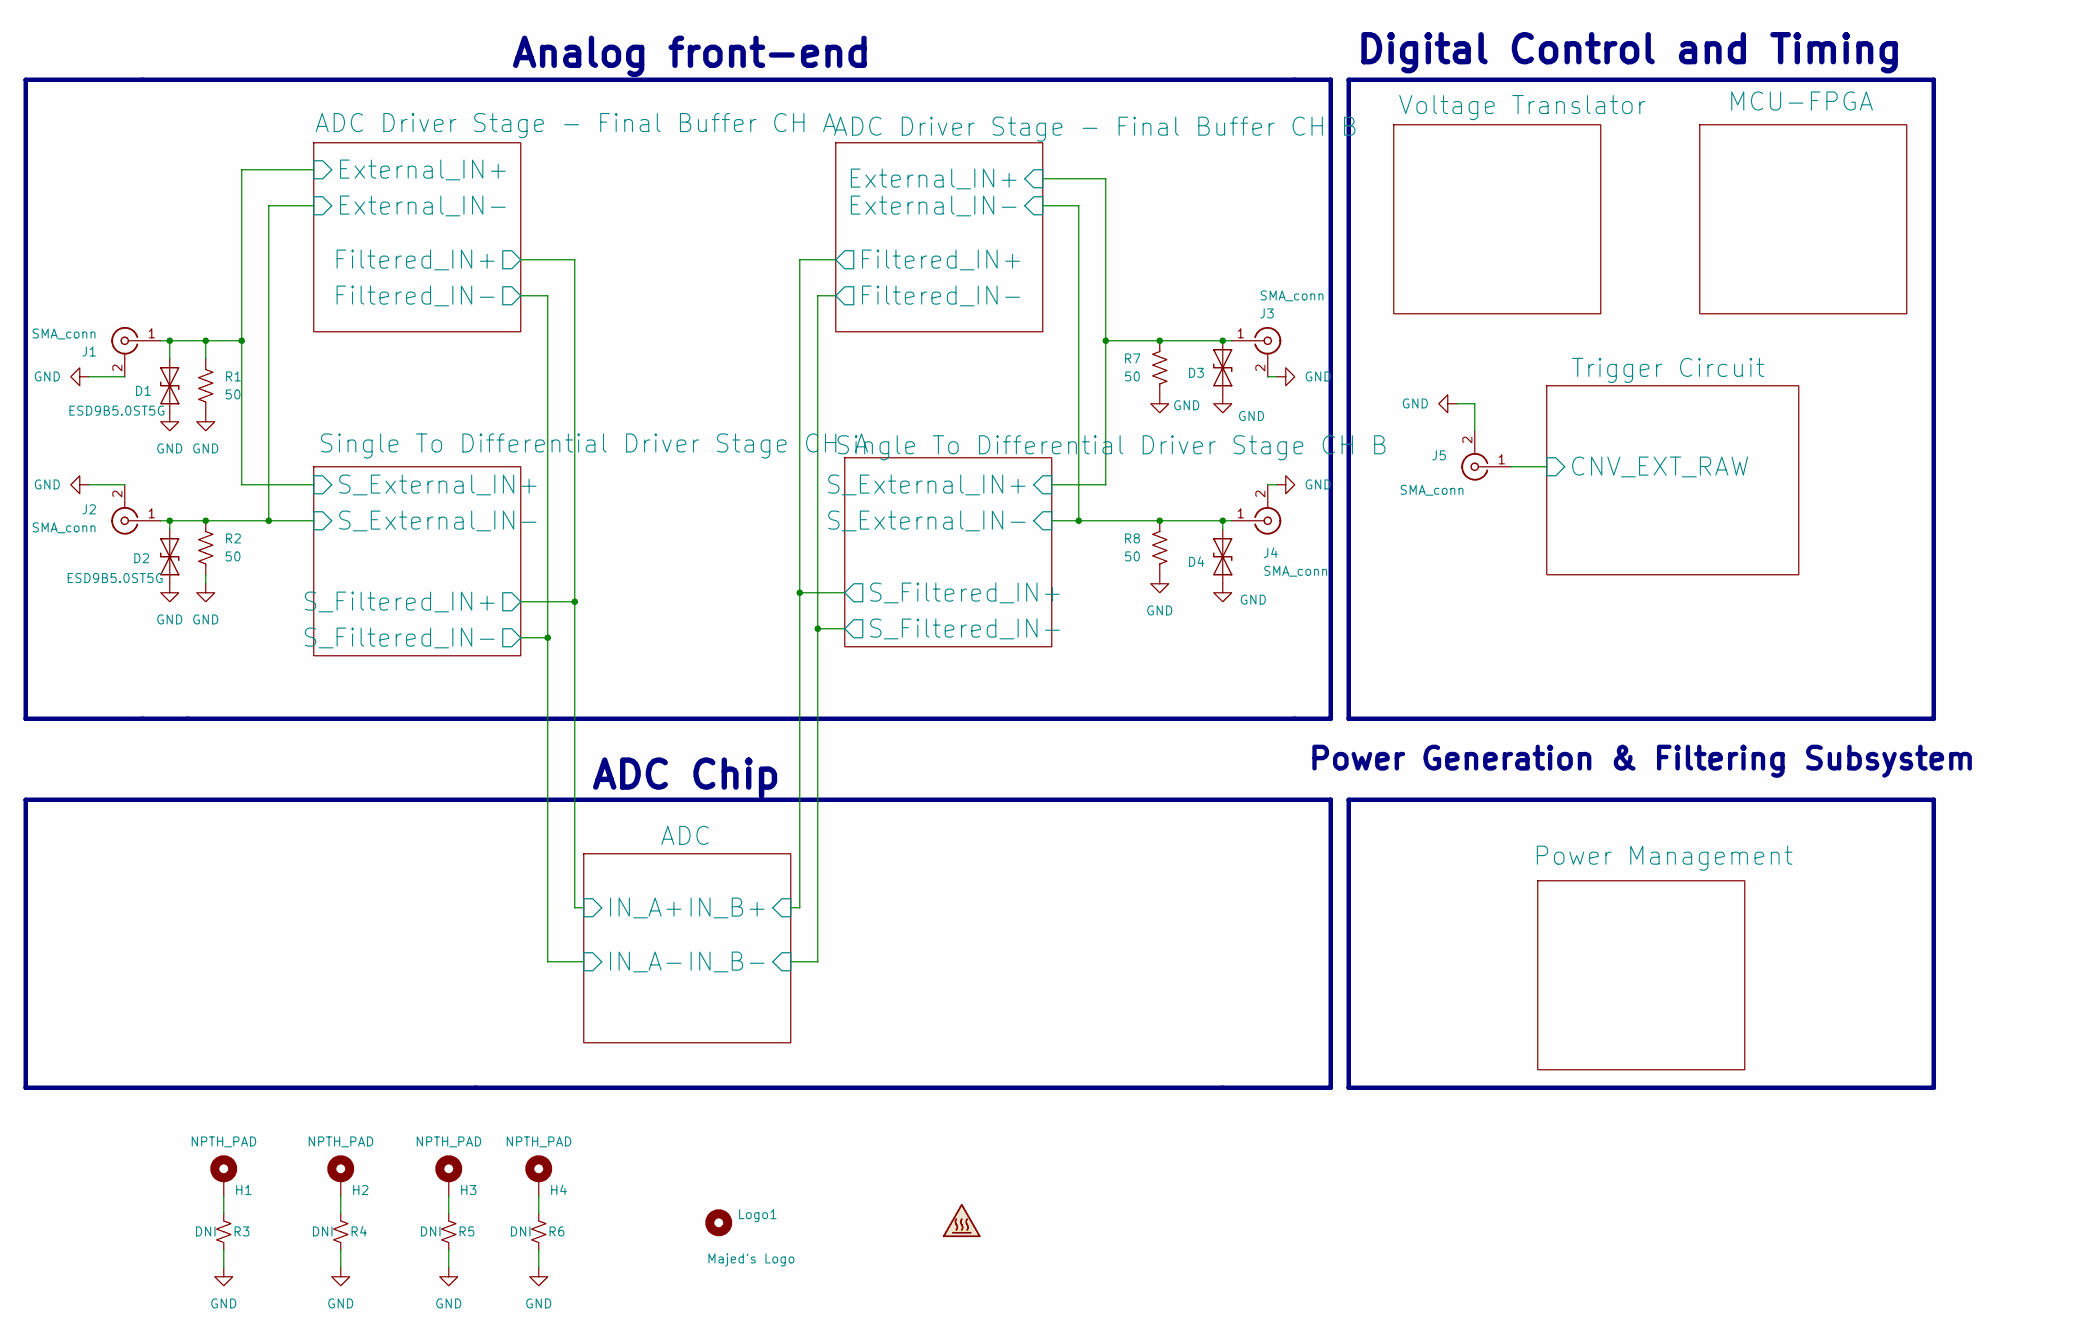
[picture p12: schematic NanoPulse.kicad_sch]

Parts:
D1, D2, D3, D4: ESD9B5.0ST5G; D_SOD-923; Mfg part # ESD9B5.0ST5G; Digikey ESD9B5.0ST5GOSCT-ND - Cut Tape
H1, H2, H3, H4: NPTH_PAD; Mounting_Wuerth_WA-SMSI-M1.6_H3.5mm_ThreadDepth2mm_NoNPTH_9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
J1, J2, J3, J4, J5: SMA_conn; SMA_Amphenol_132289_EdgeMount; Mfg part # 132289RP; Digikey ACX1427-ND
Logo1: Majed's Logo; Logo_Majed_small
R1, R2, R7, R8: 50; R_0603_1608Metric; Mfg part # RT0603BRE0750RL; Digikey 13-RT0603BRE0750RLCT-ND
R3, R4, R5, R6: DNI; R_0603_1608Metric

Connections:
/ADC Driver Stage - Final Buffer CH A/External_IN+: D1.2 (A2), J1.1 (In), R1.1; also elsewhere on the board
/ADC Driver Stage - Final Buffer CH A/External_IN-: D2.2 (A2), J2.1 (In), R2.1; also elsewhere on the board
/ADC Driver Stage - Final Buffer CH B/External_IN+: D3.2 (A2), J3.1 (In), R7.1; also elsewhere on the board
/ADC Driver Stage - Final Buffer CH B/External_IN-: D4.2 (A2), J4.1 (In), R8.1; also elsewhere on the board
/Trigger Circuit/CNV_EXT_RAW: J5.1 (In); also elsewhere on the board
GND: D1.1 (A1), D2.1 (A1), D3.1 (A1), D4.1 (A1), J1.2 (Ext), J2.2 (Ext), J3.2 (Ext), J4.2 (Ext), J5.2 (Ext), R1.2, R2.2, R3.1, R4.1, R5.1, R6.1, R7.2, R8.2; also elsewhere on the board
unnamed: H1.1, R3.2
unnamed: H2.1, R4.2
unnamed: H3.1, R5.2
unnamed: H4.1, R6.2

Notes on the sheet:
Power Generation & Filtering Subsystem
Digital Control and Timing
Analog front-end
ADC Chip

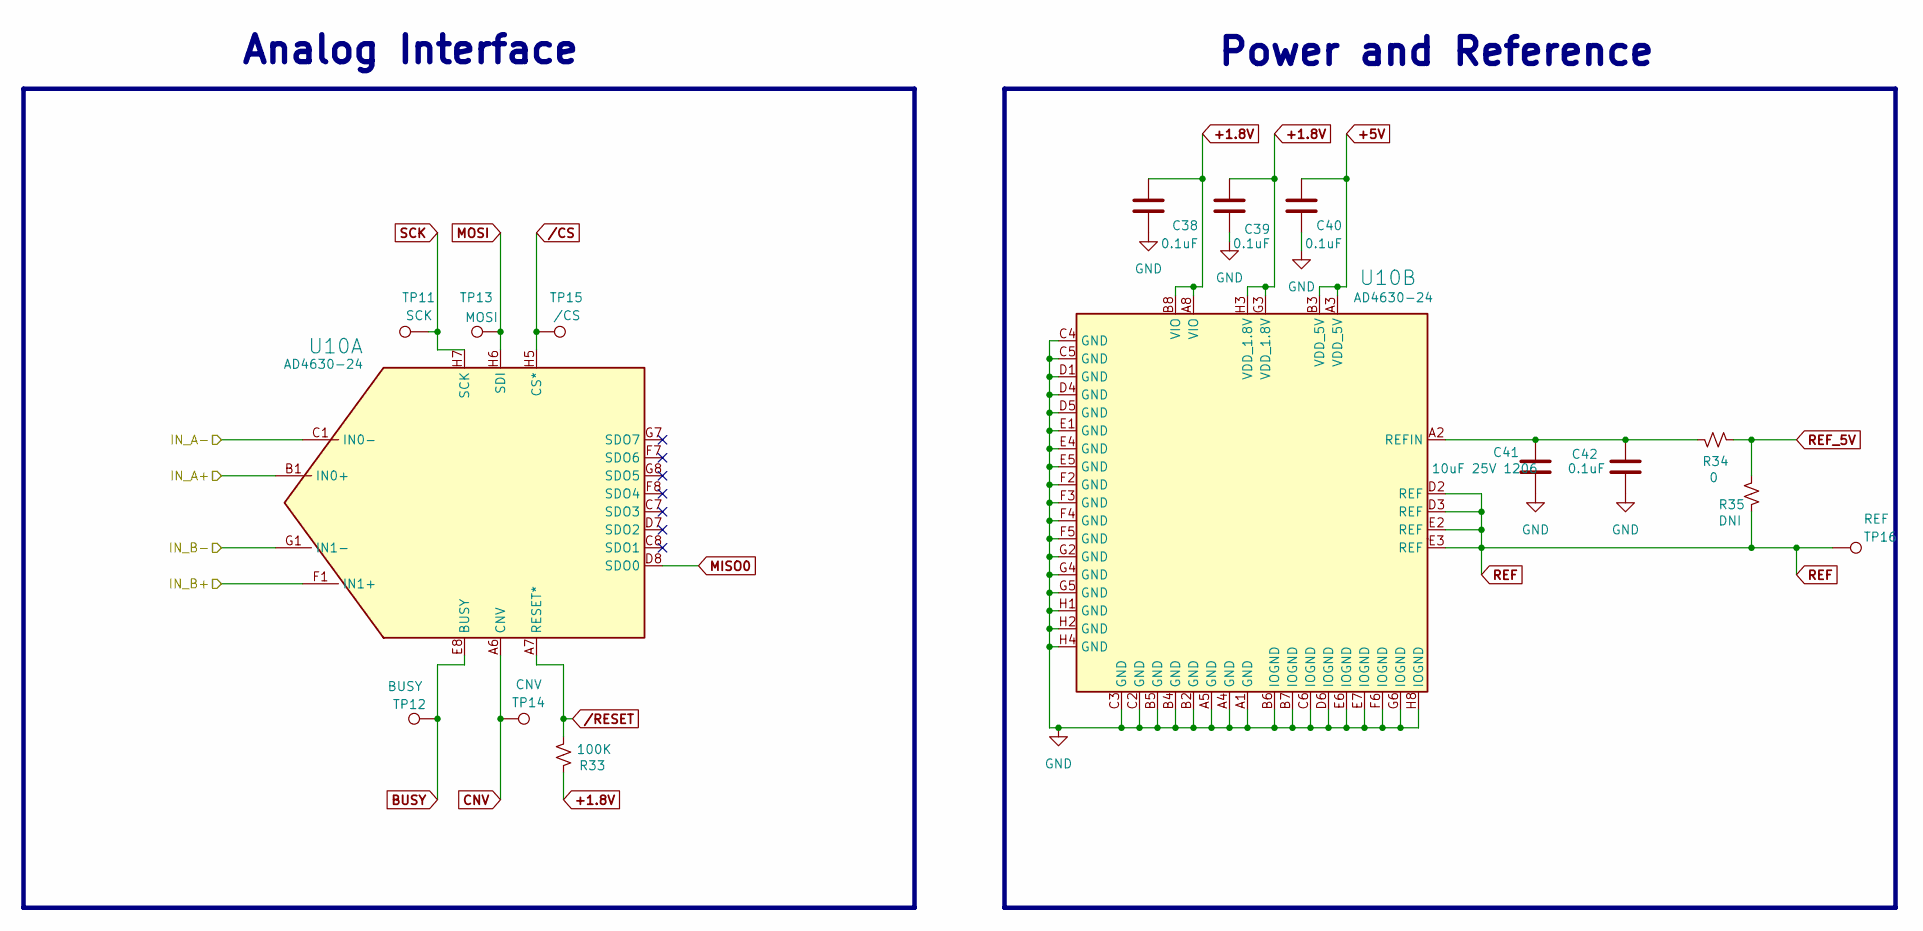
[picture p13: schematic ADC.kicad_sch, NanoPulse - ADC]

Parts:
C38, C39, C40, C42: 0.1uF; C_0603_1608Metric; Mfg part # CC0603KRX7R7BB104; Digikey 311-1088-1-ND
C41: 10uF 25V 1206; C_1206_3216Metric; Mfg part # CL31A106MAHNNNE; Digikey 1276-1181-1-ND
R33: 100K; R_0603_1608Metric; Mfg part # RC0603FR-07100KL; Digikey 311-100KHRCT-ND
R34: 0; R_0603_1608Metric; Mfg part # RC0603JR-070RL; Digikey 311-0.0GRCT-ND
R35: DNI; R_0603_1608Metric
TP11: SCK; TestPoint_Pad_1.0x1.0mm
TP12: BUSY; TestPoint_Pad_1.0x1.0mm
TP13: MOSI; TestPoint_Pad_1.0x1.0mm
TP14: CNV; TestPoint_Pad_1.0x1.0mm
TP15: /CS; TestPoint_Pad_1.0x1.0mm
TP16: REF; TestPoint_Pad_1.0x1.0mm
U10: AD4630-24; 05-08-1797_ADI-L; Mfg part # AD4630-24BBCZ-RL; Digikey 505-AD4630-24BBCZ-RLCT-ND

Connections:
+1.8V: C38.1, C39.1, R33.1, U10.A8 (VIO), U10.B8 (VIO), U10.G3 (VDD_1.8V), U10.H3 (VDD_1.8V); also elsewhere on the board
+5V: C40.1, U10.A3 (VDD_5V), U10.B3 (VDD_5V); also elsewhere on the board
/ADC Driver Stage - Final Buffer CH A/Filtered_IN+: U10.B1 (IN0+); also elsewhere on the board
/ADC Driver Stage - Final Buffer CH A/Filtered_IN-: U10.C1 (IN0-); also elsewhere on the board
/ADC Driver Stage - Final Buffer CH B/Filtered_IN+: U10.F1 (IN1+); also elsewhere on the board
/ADC Driver Stage - Final Buffer CH B/Filtered_IN-: U10.G1 (IN1-); also elsewhere on the board
BUSY: TP12.1, U10.E8 (BUSY); also elsewhere on the board
CNV: TP14.1, U10.A6 (CNV); also elsewhere on the board
GND: C38.2, C39.2, C40.2, C41.2, C42.2, U10.A1 (GND), U10.A4 (GND), U10.A5 (GND), U10.B2 (GND), U10.B4 (GND), U10.B5 (GND), U10.B6 (IOGND), U10.B7 (IOGND), U10.C2 (GND), U10.C3 (GND), U10.C4 (GND), U10.C5 (GND), U10.C6 (IOGND), U10.D1 (GND), U10.D4 (GND), U10.D5 (GND), U10.D6 (IOGND), U10.E1 (GND), U10.E4 (GND), U10.E5 (GND), U10.E6 (IOGND), U10.E7 (IOGND), U10.F2 (GND), U10.F3 (GND), U10.F4 (GND), U10.F5 (GND), U10.F6 (IOGND), U10.G2 (GND), U10.G4 (GND), U10.G5 (GND), U10.G6 (IOGND), U10.H1 (GND), U10.H2 (GND), U10.H4 (GND), U10.H8 (IOGND); also elsewhere on the board
MISO0: U10.D8 (SDO0); also elsewhere on the board
MOSI: TP13.1, U10.H6 (SDI); also elsewhere on the board
unnamed: C41.1, C42.1, R34.1, U10.A2 (REFIN)
REF: R35.2, TP16.1, U10.D2 (REF), U10.D3 (REF), U10.E2 (REF), U10.E3 (REF)
REF_5V: R34.2, R35.1; also elsewhere on the board
SCK: TP11.1, U10.H7 (SCK); also elsewhere on the board
/CS: TP15.1, U10.H5 (CS*); also elsewhere on the board
/RESET: R33.2, U10.A7 (RESET*); also elsewhere on the board

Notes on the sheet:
Analog Interface
Power and Reference

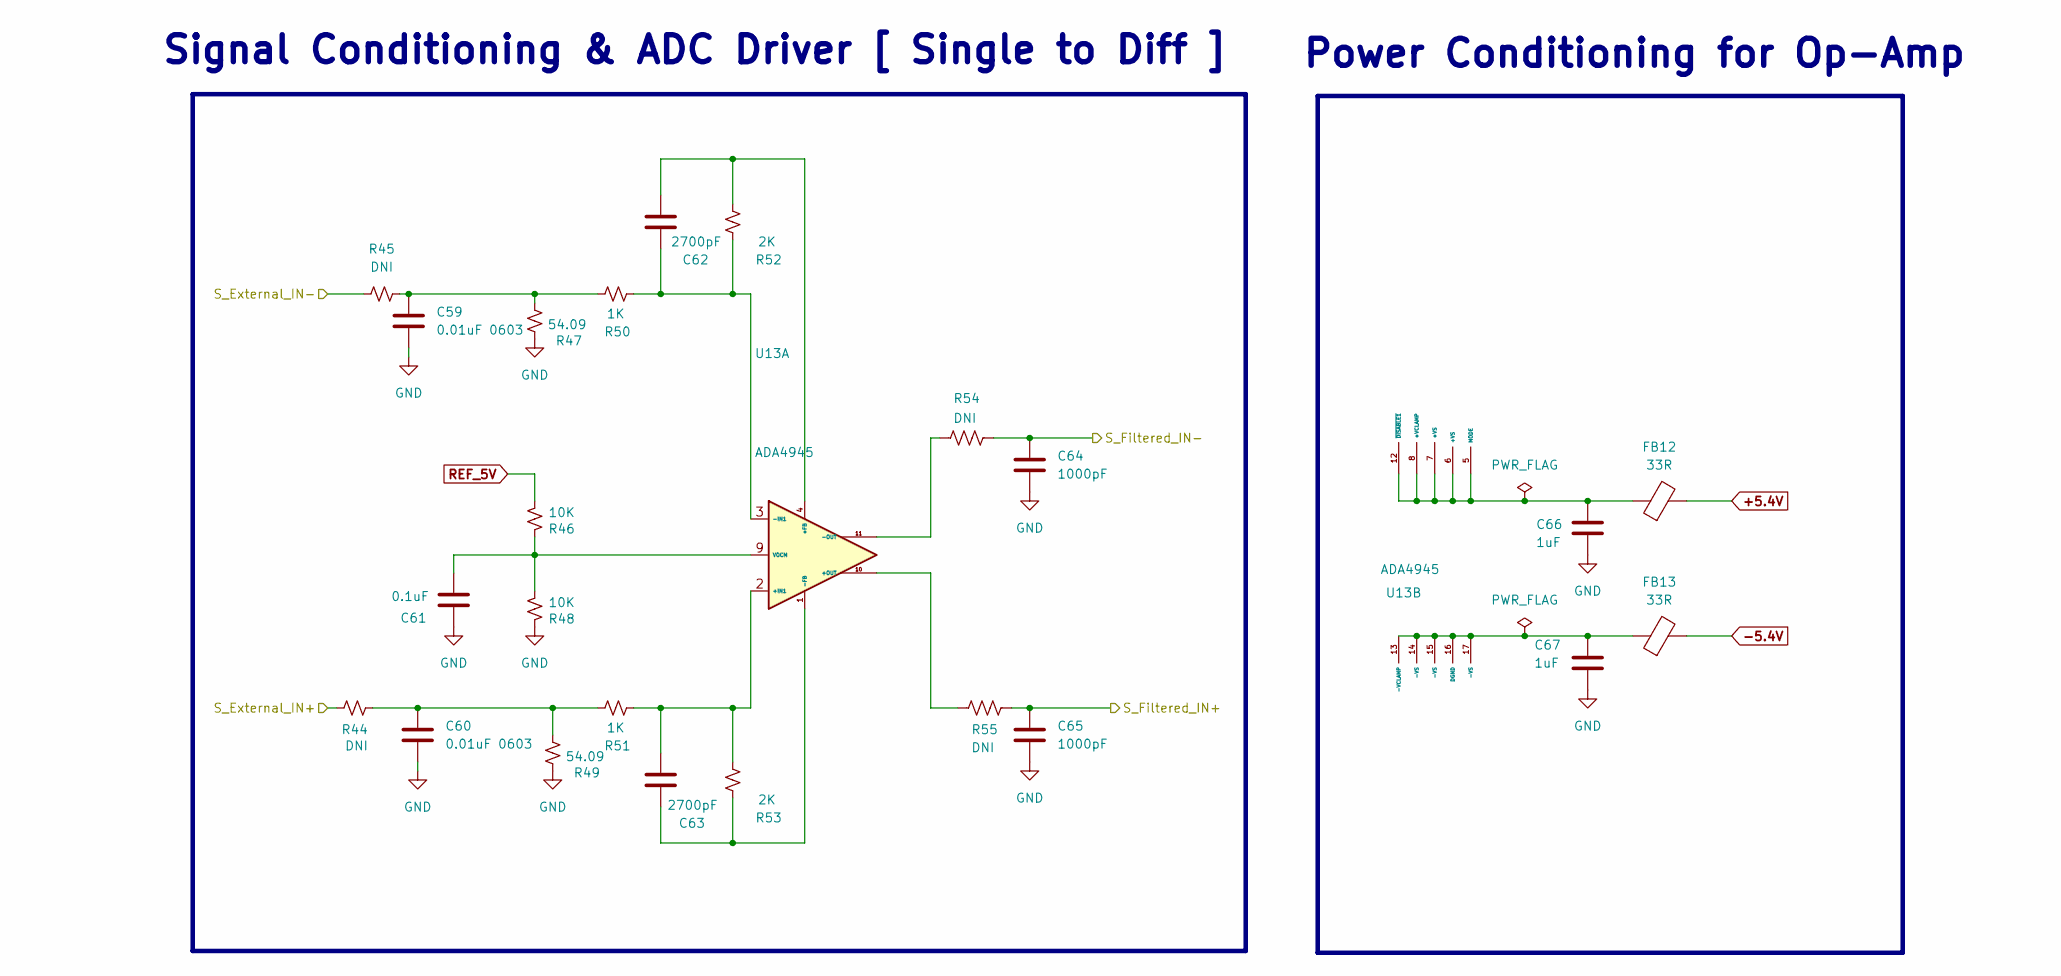
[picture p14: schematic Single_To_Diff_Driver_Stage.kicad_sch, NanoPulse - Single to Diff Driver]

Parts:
C59, C60: 0.01uF 0603; C_0603_1608Metric; Mfg part # C0603C103J5REC7411; Digikey 399-17568-1-ND
C61: 0.1uF; C_0603_1608Metric; Mfg part # CC0603KRX7R7BB104; Digikey 311-1088-1-ND
C62, C63: 2700pF; C_0805_2012Metric; Mfg part # CL21B272KBANNNC; Digikey 1276-2495-1-ND
C64, C65: 1000pF; C_0603_1608Metric; Mfg part # CL10B102KB8NNNC; Digikey 1276-1018-1-ND
C66, C67: 1uF; C_0603_1608Metric; Mfg part # CL10B105KP8NNNC; Digikey 1276-1946-1-ND
FB12, FB13: 33R; L_0603_1608Metric_Pad1.05x0.95mm_HandSolder; Mfg part # BLM18PG330SN1D; Digikey 490-5220-1-ND
R44, R45, R54, R55: DNI; R_0603_1608Metric
R46, R48: 10K; R_0603_1608Metric; Mfg part # RC0603FR-0710KL; Digikey 311-10.0KHRCT-ND
R47, R49: 54.09; R_0603_1608Metric; Mfg part # RC0603FR-0754R9L; Digikey 311-54.9HRCT-ND
R50, R51: 1K; R_0603_1608Metric; Mfg part # RC0603FR-071KL; Digikey 311-1.00KHRCT-ND
R52, R53: 2K; R_0603_1608Metric; Mfg part # RC0603FR-071KL; Digikey 311-2.00KHRCT-ND
U13: ADA4945; LFCSP16_ADA4945-1ACPZ-R2_ADI-L; Mfg part # ADA4945-1ACPZ-RL; Digikey 05-ADA4945-1ACPZ-RLCT-ND

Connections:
+5.4V: FB12.2; also elsewhere on the board
-5.4V: FB13.2; also elsewhere on the board
/ADC Driver Stage - Final Buffer CH A/External_IN+: R44.2; also elsewhere on the board
/ADC Driver Stage - Final Buffer CH A/External_IN-: R45.2; also elsewhere on the board
/ADC Driver Stage - Final Buffer CH A/Filtered_IN+: C65.1, R55.2; also elsewhere on the board
/ADC Driver Stage - Final Buffer CH A/Filtered_IN-: C64.1, R54.2; also elsewhere on the board
GND: C59.2, C60.2, C61.1, C64.2, C65.2, C66.2, C67.2, R47.2, R48.2, R49.2; also elsewhere on the board
unnamed: C59.1, R45.1, R47.1, R50.2
unnamed: C60.1, R44.1, R49.1, R51.2
unnamed: C62.2, R52.1, U13.4 (+FB)
unnamed: C63.2, R51.1, R53.1, U13.2 (+IN1)
unnamed: R55.1, U13.10 (+OUT)
unnamed: C63.1, R53.2, U13.1 (-FB)
unnamed: C62.1, R50.1, R52.2, U13.3 (-IN1)
unnamed: R54.1, U13.11 (-OUT)
unnamed: C61.2, R46.2, R48.1, U13.9 (VOCM)
unnamed: C66.1, FB12.1, U13.5 (MODE), U13.6 (+VS), U13.7 (+VS), U13.8 (+VCLAMP), U13.12 (~DISABLE1)
unnamed: C67.1, FB13.1, U13.13 (-VCLAMP), U13.14 (-VS), U13.15 (-VS), U13.16 (DGND), U13.17 (-VS)
REF_5V: R46.1; also elsewhere on the board

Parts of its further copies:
C68, C69: 0.01uF 0603; C_0603_1608Metric; Mfg part # C0603C103J5REC7411; Digikey 399-17568-1-ND
C70: 0.1uF; C_0603_1608Metric; Mfg part # CC0603KRX7R7BB104; Digikey 311-1088-1-ND
C71, C72: 2700pF; C_0805_2012Metric; Mfg part # CL21B272KBANNNC; Digikey 1276-2495-1-ND
C73, C74: 1000pF; C_0603_1608Metric; Mfg part # CL10B102KB8NNNC; Digikey 1276-1018-1-ND
C75, C76: 1uF; C_0603_1608Metric; Mfg part # CL10B105KP8NNNC; Digikey 1276-1946-1-ND
FB14, FB15: 33R; L_0603_1608Metric_Pad1.05x0.95mm_HandSolder; Mfg part # BLM18PG330SN1D; Digikey 490-5220-1-ND
R56, R57, R66, R67: DNI; R_0603_1608Metric
R58, R60: 10K; R_0603_1608Metric; Mfg part # RC0603FR-0710KL; Digikey 311-10.0KHRCT-ND
R59, R61: 54.09; R_0603_1608Metric; Mfg part # RC0603FR-0754R9L; Digikey 311-54.9HRCT-ND
R62, R63: 1K; R_0603_1608Metric; Mfg part # RC0603FR-071KL; Digikey 311-1.00KHRCT-ND
R64, R65: 2K; R_0603_1608Metric; Mfg part # RC0603FR-071KL; Digikey 311-2.00KHRCT-ND
U14: ADA4945; LFCSP16_ADA4945-1ACPZ-R2_ADI-L; Mfg part # ADA4945-1ACPZ-RL; Digikey 05-ADA4945-1ACPZ-RLCT-ND

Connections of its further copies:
+5.4V: FB14.2; also elsewhere on the board
-5.4V: FB15.2; also elsewhere on the board
/ADC Driver Stage - Final Buffer CH B/External_IN+: R56.2; also elsewhere on the board
/ADC Driver Stage - Final Buffer CH B/External_IN-: R57.2; also elsewhere on the board
/ADC Driver Stage - Final Buffer CH B/Filtered_IN+: C74.1, R67.2; also elsewhere on the board
/ADC Driver Stage - Final Buffer CH B/Filtered_IN-: C73.1, R66.2; also elsewhere on the board
GND: C68.2, C69.2, C70.1, C73.2, C74.2, C75.2, C76.2, R59.2, R60.2, R61.2; also elsewhere on the board
unnamed: C68.1, R57.1, R59.1, R62.2
unnamed: C69.1, R56.1, R61.1, R63.2
unnamed: C71.2, R64.1, U14.4 (+FB)
unnamed: C72.2, R63.1, R65.1, U14.2 (+IN1)
unnamed: R67.1, U14.10 (+OUT)
unnamed: C72.1, R65.2, U14.1 (-FB)
unnamed: C71.1, R62.1, R64.2, U14.3 (-IN1)
unnamed: R66.1, U14.11 (-OUT)
unnamed: C70.2, R58.2, R60.1, U14.9 (VOCM)
unnamed: C75.1, FB14.1, U14.5 (MODE), U14.6 (+VS), U14.7 (+VS), U14.8 (+VCLAMP), U14.12 (~DISABLE1)
unnamed: C76.1, FB15.1, U14.13 (-VCLAMP), U14.14 (-VS), U14.15 (-VS), U14.16 (DGND), U14.17 (-VS)
REF_5V: R58.1; also elsewhere on the board

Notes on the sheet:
Power Conditioning for Op-Amp
Signal Conditioning & ADC Driver [ Single to Diff ]

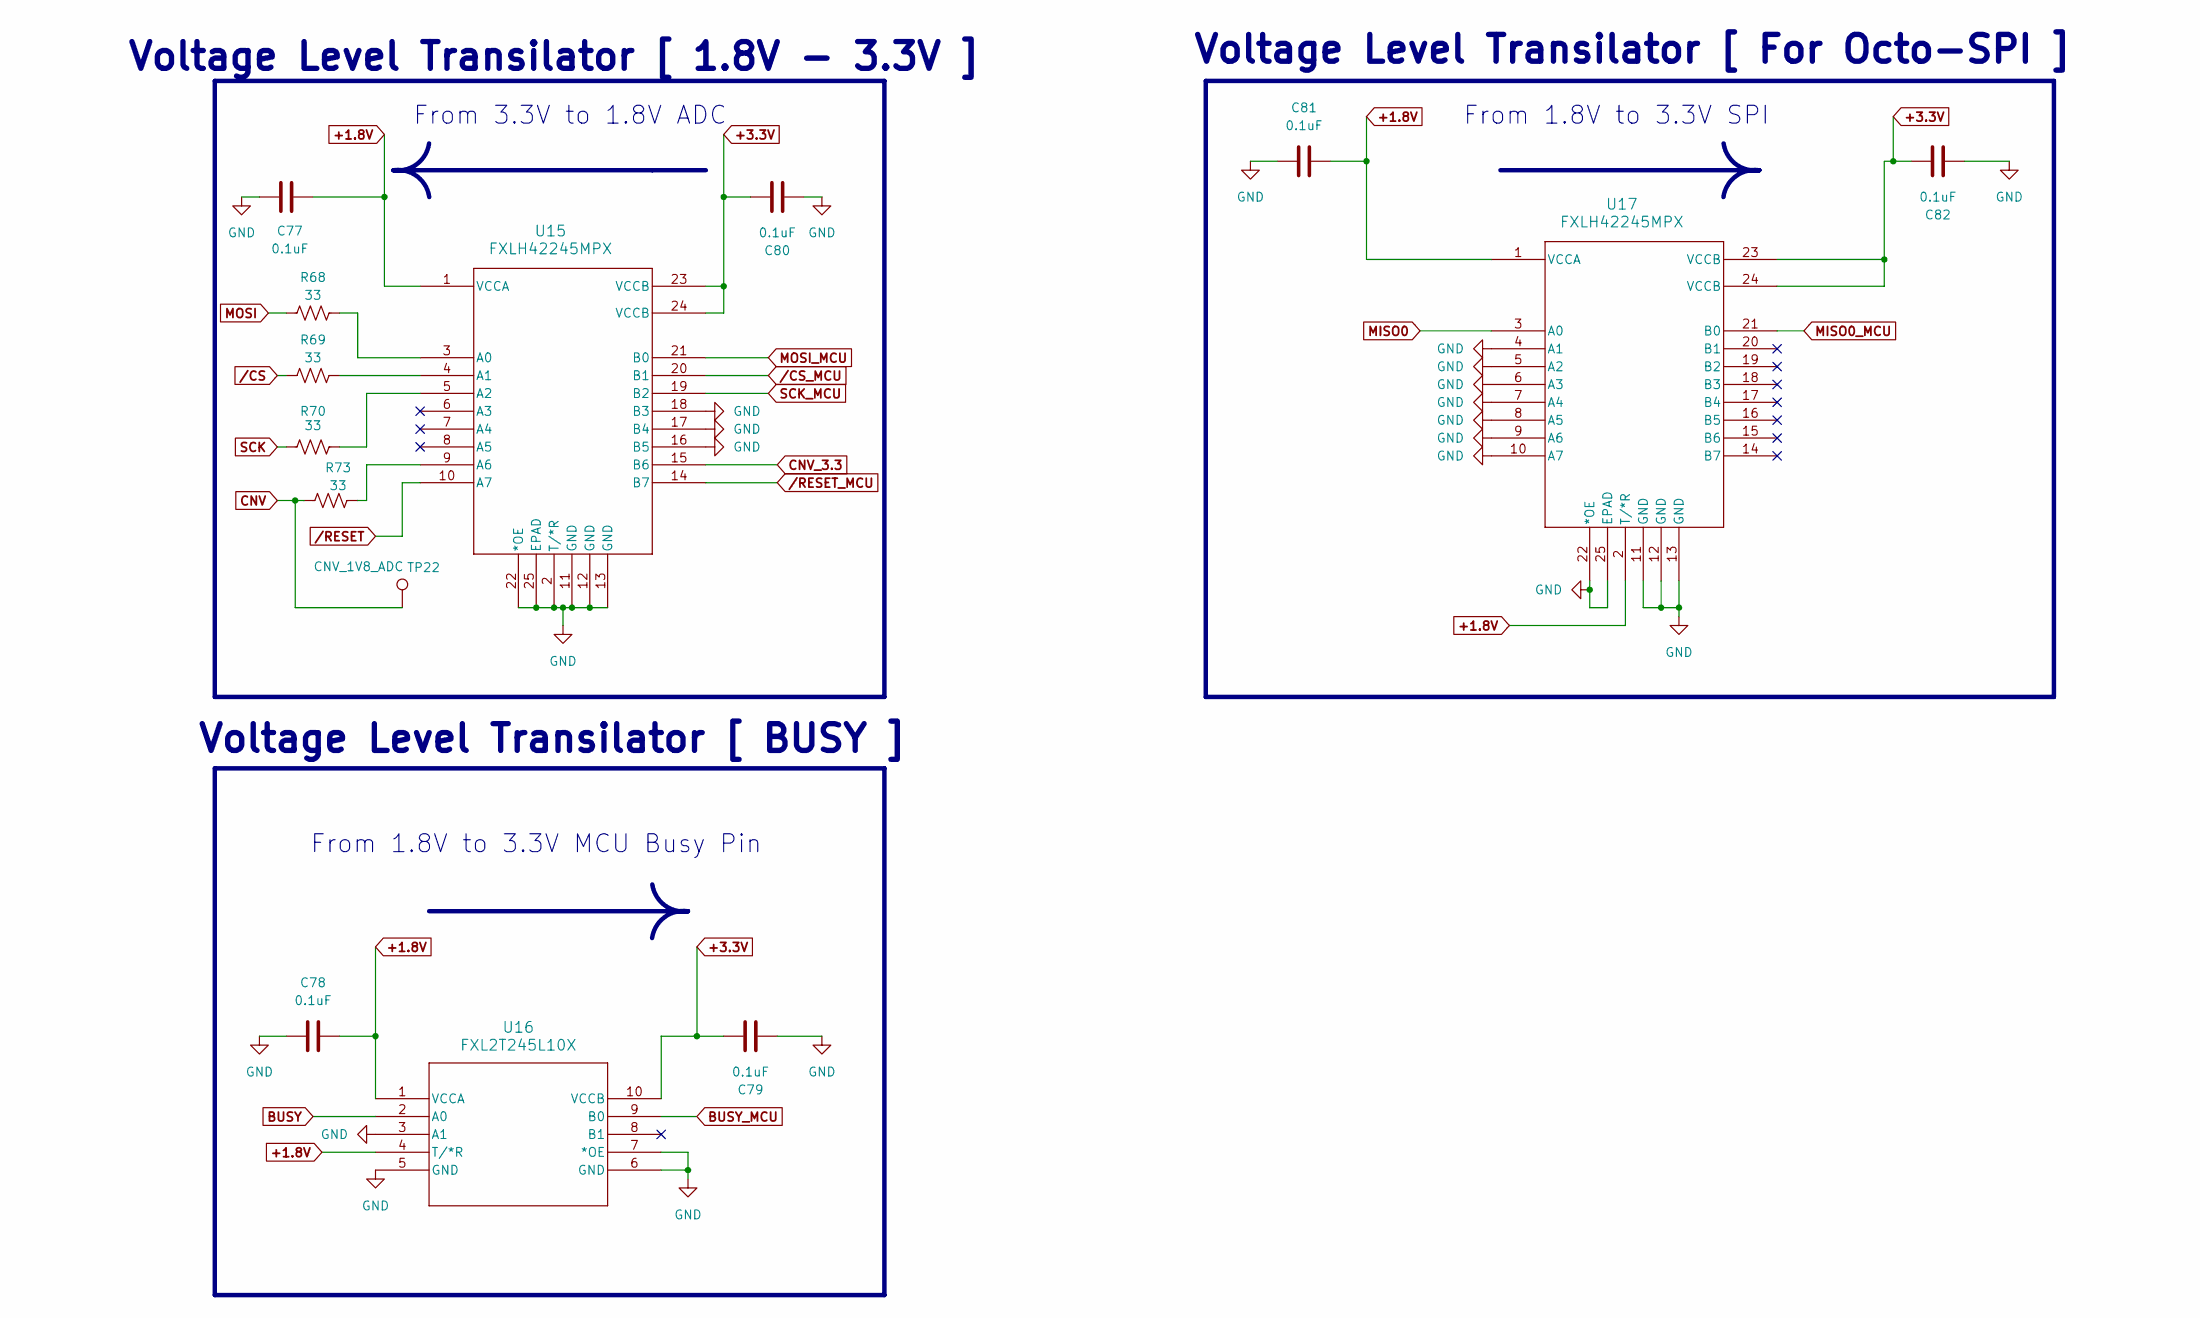
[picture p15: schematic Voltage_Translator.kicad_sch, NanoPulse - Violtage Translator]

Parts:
C77, C78, C79, C80, C81, C82: 0.1uF; C_0603_1608Metric; Mfg part # CC0603KRX7R7BB104; Digikey 311-1088-1-ND
R68, R69, R70, R73: 33; R_0603_1608Metric; Mfg part # RC0603FR-072KL; Digikey 311-33GRCT-ND
TP22: CNV_1V8_ADC; TestPoint_Pad_1.0x1.0mm
U15, U17: FXLH42245MPX; MLP24_4P5X3P5_ONS; Mfg part # FXLH42245MPX; Digikey FXLH42245MPXCT-ND
U16: FXL2T245L10X; MICROPAK10_2P1X1P6_ONS-L; Mfg part # FXL2T245L10X; Digikey FXL2T245L10XCT-ND

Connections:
+1.8V: C77.1, C78.1, C81.1, U15.1 (VCCA), U16.1 (VCCA), U16.4 (T/*R), U17.1 (VCCA), U17.2 (T/*R); also elsewhere on the board
+3.3V: C79.1, C80.1, C82.1, U15.23 (VCCB), U15.24 (VCCB), U16.10 (VCCB), U17.23 (VCCB), U17.24 (VCCB); also elsewhere on the board
BUSY: U16.2 (A0); also elsewhere on the board
BUSY_MCU: U16.9 (B0); also elsewhere on the board
CNV: R73.2, TP22.1; also elsewhere on the board
CNV_3.3: U15.15 (B6); also elsewhere on the board
GND: C77.2, C78.2, C79.2, C80.2, C81.2, C82.2, U15.2 (T/*R), U15.11 (GND), U15.12 (GND), U15.13 (GND), U15.16 (B5), U15.17 (B4), U15.18 (B3), U15.22 (*OE), U15.25 (EPAD), U16.3 (A1), U16.5 (GND), U16.6 (GND), U16.7 (*OE), U17.4 (A1), U17.5 (A2), U17.6 (A3), U17.7 (A4), U17.8 (A5), U17.9 (A6), U17.10 (A7), U17.11 (GND), U17.12 (GND), U17.13 (GND), U17.22 (*OE), U17.25 (EPAD); also elsewhere on the board
MISO0: U17.3 (A0); also elsewhere on the board
MISO0_MCU: U17.21 (B0); also elsewhere on the board
MOSI: R68.1; also elsewhere on the board
MOSI_MCU: U15.21 (B0); also elsewhere on the board
unnamed: R68.2, U15.3 (A0)
unnamed: R69.2, U15.4 (A1)
unnamed: R70.2, U15.5 (A2)
unnamed: R73.1, U15.9 (A6)
SCK: R70.1; also elsewhere on the board
SCK_MCU: U15.19 (B2); also elsewhere on the board
/CS: R69.1; also elsewhere on the board
/CS_MCU: U15.20 (B1); also elsewhere on the board
/RESET: U15.10 (A7); also elsewhere on the board
/RESET_MCU: U15.14 (B7); also elsewhere on the board

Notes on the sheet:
Voltage Level Transilator [ BUSY ]
Voltage Level Transilator [ 1.8V - 3.3V ]
Voltage Level Transilator [ For Octo-SPI ]
From 3.3V to 1.8V ADC
From 1.8V to 3.3V MCU Busy Pin
From 1.8V to 3.3V SPI

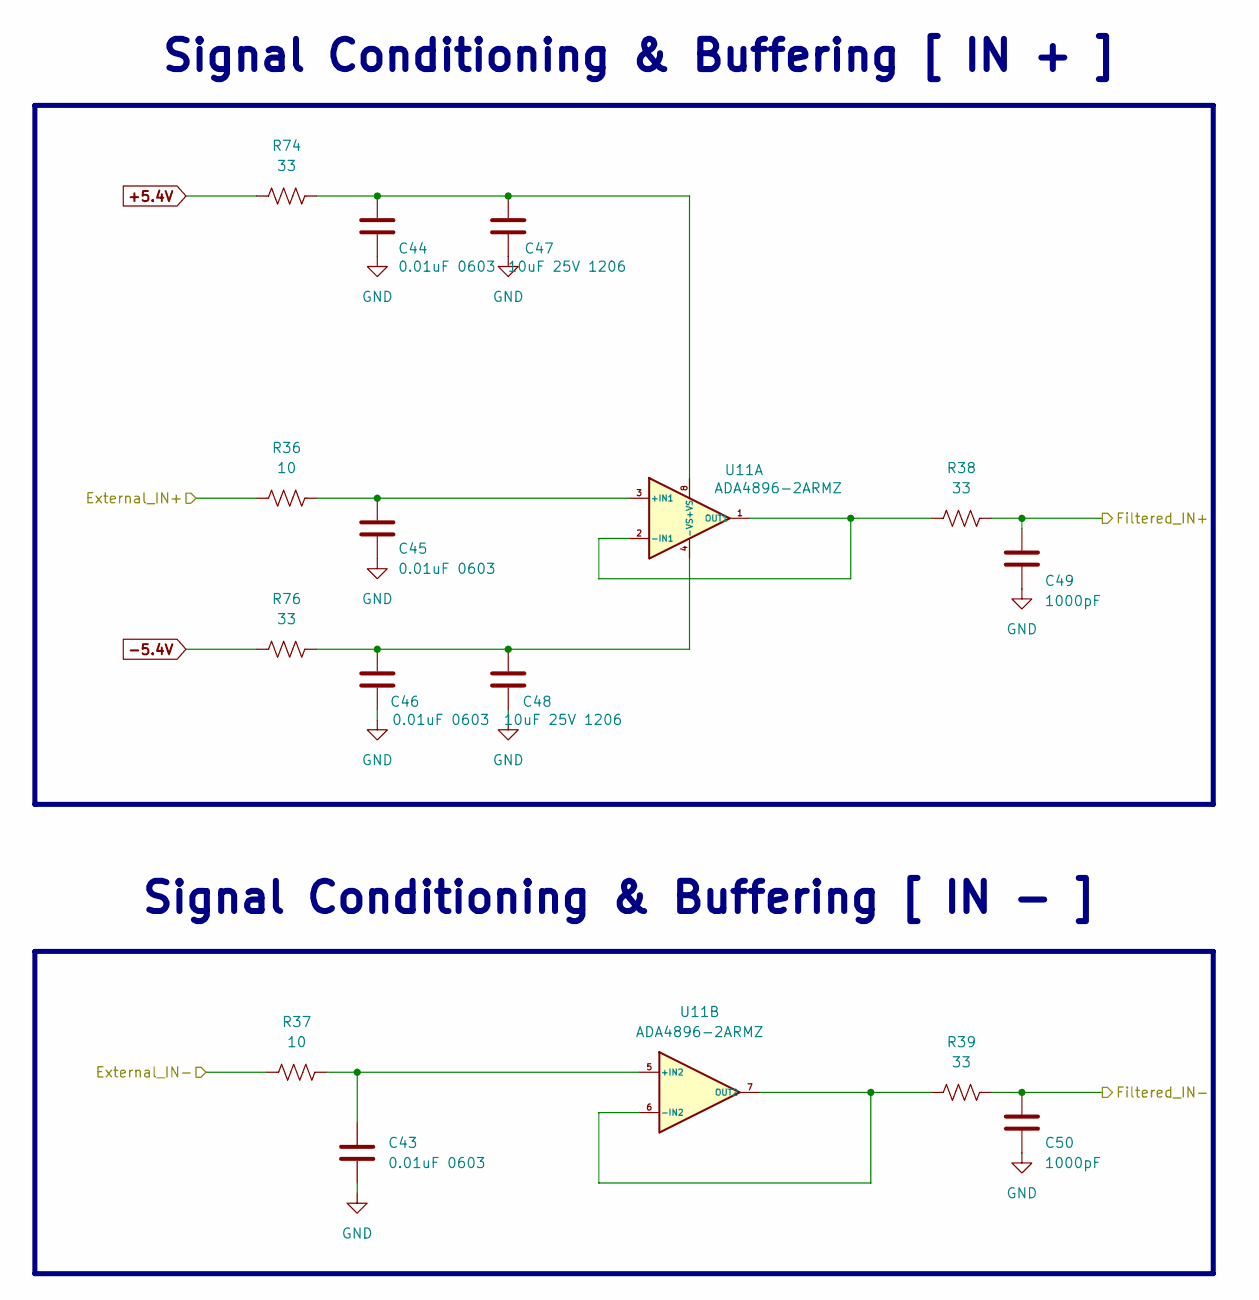
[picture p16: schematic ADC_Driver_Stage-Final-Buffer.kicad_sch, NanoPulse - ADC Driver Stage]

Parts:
C43, C44, C45, C46: 0.01uF 0603; C_0603_1608Metric; Mfg part # C0603C103J5REC7411; Digikey 399-17568-1-ND
C47, C48: 10uF 25V 1206; C_1206_3216Metric; Mfg part # CL31A106MAHNNNE; Digikey 1276-1181-1-ND
C49, C50: 1000pF; C_0603_1608Metric; Mfg part # CL10B102KB8NNNC; Digikey 1276-1018-1-ND
R36, R37: 10; R_0805_2012Metric; Mfg part # RC0805FR-0710RL; Digikey 311-10.0CRCT-ND
R38, R39, R74, R76: 33; R_0603_1608Metric; Mfg part # RC0603FR-072KL; Digikey 311-33GRCT-ND
U11: ADA4896-2ARMZ; RM_8_ADI; Mfg part # ADA4896-2ARMZ; Digikey 505-ADA4896-2ARMZ-ND

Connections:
+5.4V: R74.2; also elsewhere on the board
-5.4V: R76.2; also elsewhere on the board
/ADC Driver Stage - Final Buffer CH A/External_IN+: R36.1; also elsewhere on the board
/ADC Driver Stage - Final Buffer CH A/External_IN-: R37.2; also elsewhere on the board
/ADC Driver Stage - Final Buffer CH A/Filtered_IN+: C49.1, R38.1; also elsewhere on the board
/ADC Driver Stage - Final Buffer CH A/Filtered_IN-: C50.1, R39.1; also elsewhere on the board
GND: C43.2, C44.2, C45.2, C46.2, C47.2, C48.2, C49.2, C50.2; also elsewhere on the board
unnamed: C45.1, R36.2, U11.3 (+IN1)
unnamed: C44.1, C47.1, R74.1, U11.8 (+VS)
unnamed: R38.2, U11.1 (OUT1), U11.2 (-IN1)
unnamed: C46.1, C48.1, R76.1, U11.4 (-VS)
unnamed: C43.1, R37.1, U11.5 (+IN2)
unnamed: R39.2, U11.6 (-IN2), U11.7 (OUT2)

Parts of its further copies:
C51, C52, C53, C54: 0.01uF 0603; C_0603_1608Metric; Mfg part # C0603C103J5REC7411; Digikey 399-17568-1-ND
C55, C56: 10uF 25V 1206; C_1206_3216Metric; Mfg part # CL31A106MAHNNNE; Digikey 1276-1181-1-ND
C57, C58: 1000pF; C_0603_1608Metric; Mfg part # CL10B102KB8NNNC; Digikey 1276-1018-1-ND
R40, R41: 10; R_0805_2012Metric; Mfg part # RC0805FR-0710RL; Digikey 311-10.0CRCT-ND
R42, R43, R75, R77: 33; R_0603_1608Metric; Mfg part # RC0603FR-072KL; Digikey 311-33GRCT-ND
U12: ADA4896-2ARMZ; RM_8_ADI; Mfg part # ADA4896-2ARMZ; Digikey 505-ADA4896-2ARMZ-ND

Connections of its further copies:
+5.4V: R75.2; also elsewhere on the board
-5.4V: R77.2; also elsewhere on the board
/ADC Driver Stage - Final Buffer CH B/External_IN+: R40.1; also elsewhere on the board
/ADC Driver Stage - Final Buffer CH B/External_IN-: R41.2; also elsewhere on the board
/ADC Driver Stage - Final Buffer CH B/Filtered_IN+: C57.1, R42.1; also elsewhere on the board
/ADC Driver Stage - Final Buffer CH B/Filtered_IN-: C58.1, R43.1; also elsewhere on the board
GND: C51.2, C52.2, C53.2, C54.2, C55.2, C56.2, C57.2, C58.2; also elsewhere on the board
unnamed: C53.1, R40.2, U12.3 (+IN1)
unnamed: C52.1, C55.1, R75.1, U12.8 (+VS)
unnamed: R42.2, U12.1 (OUT1), U12.2 (-IN1)
unnamed: C54.1, C56.1, R77.1, U12.4 (-VS)
unnamed: C51.1, R41.1, U12.5 (+IN2)
unnamed: R43.2, U12.6 (-IN2), U12.7 (OUT2)

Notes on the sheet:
Signal Conditioning & Buffering [ IN + ]
Signal Conditioning & Buffering [ IN - ]

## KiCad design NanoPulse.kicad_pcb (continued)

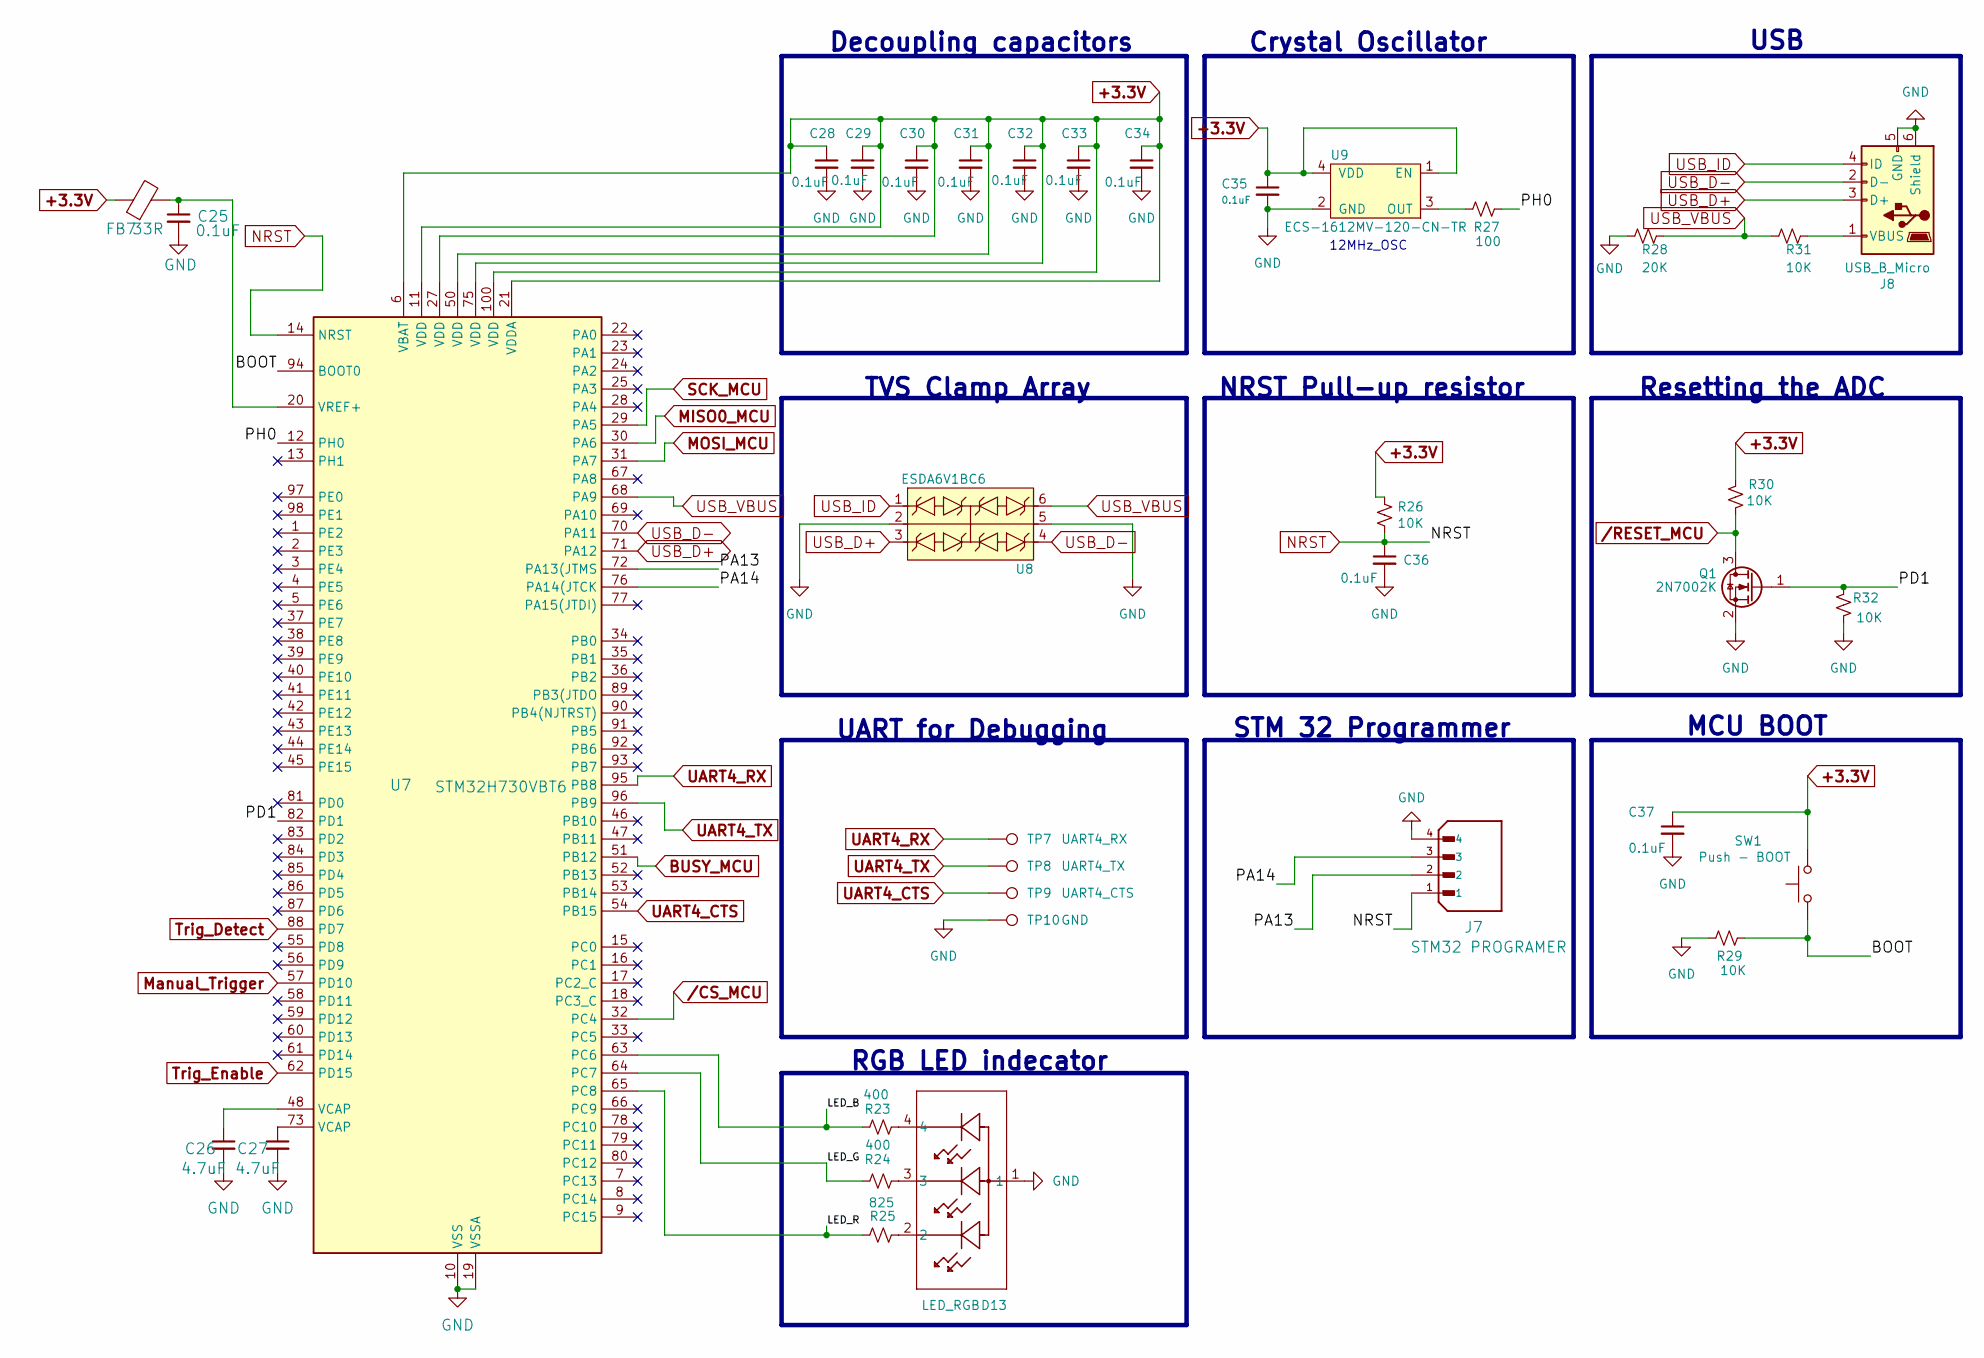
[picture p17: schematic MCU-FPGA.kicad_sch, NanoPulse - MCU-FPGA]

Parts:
C25, C28, C29, C30, C31, C32, C33, C34, C35, C36, C37: 0.1uF; C_0603_1608Metric; Mfg part # CC0603KRX7R7BB104; Digikey 311-1088-1-ND
C26, C27: 4.7uF; C_0805_2012Metric; Mfg part # CL21A475KAQNNNE; Digikey 1276-1244-1-ND
D13: LED_RGB; APHF1608SEEQBDZGKC_KNB-L; Mfg part # APHF1608SEEQBDZGKC; Digikey 754-2144-2-ND
FB7: 33R; L_0603_1608Metric_Pad1.05x0.95mm_HandSolder; Mfg part # BLM18PG330SN1D; Digikey 490-5220-1-ND
J7: STM32 PROGRAMER; SPARKFUN_PRT-14417; PARTREV NA; Digikey 1568-14417-ND
J8: USB_B_Micro; USB_Micro-B_Molex-105017-0001; Mfg part # 0473461001; Digikey WM11228CT-ND
Q1: 2N7002K; SOT-23; Mfg part # 2N7002LT1G; Digikey 2N7002LT1GOSCT-ND
R23, R24: 400; R_0603_1608Metric; Mfg part # PAT0603E4000BST1; Digikey PAT400ACT-ND
R25: 825; R_0603_1608Metric; Mfg part # RC0603FR-07825RL; Digikey 311-825HRCT-ND
R26, R29, R30, R31, R32: 10K; R_0603_1608Metric; Mfg part # RC0603FR-0710KL; Digikey 311-10.0KHRCT-ND
R27: 100; R_0603_1608Metric; Mfg part # RC0603FR-07100RL; Digikey 311-100HRCT-ND
R28: 20K; R_0603_1608Metric; Mfg part # RC0603FR-0720KL; Digikey 311-20.0KHRCT-ND
SW1: Push - BOOT; SW_Tactile_SPST_NO_Straight_CK_PTS636Sx25SMTRLFS; Mfg part # TL59NF160Q; Digikey EG2532CT-ND
TP7: UART4_RX; TestPoint_Pad_1.0x1.0mm
TP8: UART4_TX; TestPoint_Pad_1.0x1.0mm
TP9: UART4_CTS; TestPoint_Pad_1.0x1.0mm
TP10: GND; TestPoint_Pad_1.0x1.0mm
U7: STM32H730VBT6; LQFP-100_14x14mm_P0.5mm; Mfg part # STM32H730VBT6; Digikey 497-STM32H730VBT6-ND
U8: ESDA6V1BC6; SOT-23-6; Mfg part # STMicroelectronics; Digikey 497-6635-1-ND
U9: ECS-1612MV-120-CN-TR; Mfg part # ECS-1612MV-120-CN-TR; Digikey XC2833CT-ND

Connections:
+3.3V: C28.1, C29.1, C30.1, C31.1, C32.1, C33.1, C34.1, C35.1, C37.1, FB7.1, R26.1, R30.1, SW1.2, U7.6 (VBAT), U7.11 (VDD), U7.21 (VDDA), U7.27 (VDD), U7.50 (VDD), U7.75 (VDD), U7.100 (VDD), U9.1 (EN), U9.4 (VDD); also elsewhere on the board
/MCU-FPGA/BOOT: R29.1, SW1.1, U7.94 (BOOT0)
/MCU-FPGA/LED_B: R23.1, U7.63 (PC6)
/MCU-FPGA/LED_G: R24.1, U7.64 (PC7)
/MCU-FPGA/LED_R: R25.1, U7.65 (PC8)
/MCU-FPGA/PA13: J7.2, U7.72 (PA13(JTMS)
/MCU-FPGA/PA14: J7.3, U7.76 (PA14(JTCK)
/MCU-FPGA/PD1: Q1.1 (G), R32.1, U7.82 (PD1)
/MCU-FPGA/PH0: R27.1, U7.12 (PH0)
BUSY_MCU: U7.51 (PB12); also elsewhere on the board
GND: C25.2, C26.2, C27.2, C28.2, C29.2, C30.2, C31.2, C32.2, C33.2, C34.2, C35.2, C36.2, C37.2, D13.1, J7.4, J8.5 (GND), J8.6 (Shield), Q1.2 (S), R28.2, R29.2, R32.2, TP10.1, U7.10 (VSS), U7.19 (VSSA), U7.26 (VSS), U7.49 (VSS), U7.74 (VSS), U7.99 (VSS), U8.2, U8.5, U9.2 (GND); also elsewhere on the board
MISO0_MCU: U7.30 (PA6); also elsewhere on the board
MOSI_MCU: U7.31 (PA7); also elsewhere on the board
Manual_Trigger: U7.57 (PD10); also elsewhere on the board
NRST: C36.1, J7.1, R26.2, U7.14 (NRST)
unnamed: C26.1, U7.48 (VCAP)
unnamed: C27.1, U7.73 (VCAP)
unnamed: D13.2, R25.2
unnamed: D13.3, R24.2
unnamed: D13.4, R23.2
unnamed: J8.1 (VBUS), R31.1
unnamed: C25.1, FB7.2, U7.20 (VREF+)
unnamed: R27.2, U9.3 (OUT)
SCK_MCU: U7.29 (PA5); also elsewhere on the board
Trig_Detect: U7.88 (PD7); also elsewhere on the board
Trig_Enable: U7.62 (PD15); also elsewhere on the board
UART4_CTS: TP9.1, U7.54 (PB15)
UART4_RX: TP7.1, U7.95 (PB8)
UART4_TX: TP8.1, U7.96 (PB9)
USB_D+: J8.3 (D+), U7.71 (PA12), U8.3
USB_D-: J8.2 (D-), U7.70 (PA11), U8.4
USB_ID: J8.4 (ID), U8.1
USB_VBUS: R28.1, R31.2, U7.68 (PA9), U8.6
/CS_MCU: U7.32 (PC4); also elsewhere on the board
/RESET_MCU: Q1.3 (D), R30.2; also elsewhere on the board

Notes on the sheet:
NRST Pull-up resistor
MCU BOOT
STM 32 Programmer
USB
RGB LED indecator
12MHz_OSC
Decoupling capacitors
TVS Clamp Array
UART for Debugging
Resetting the ADC
Crystal Oscillator

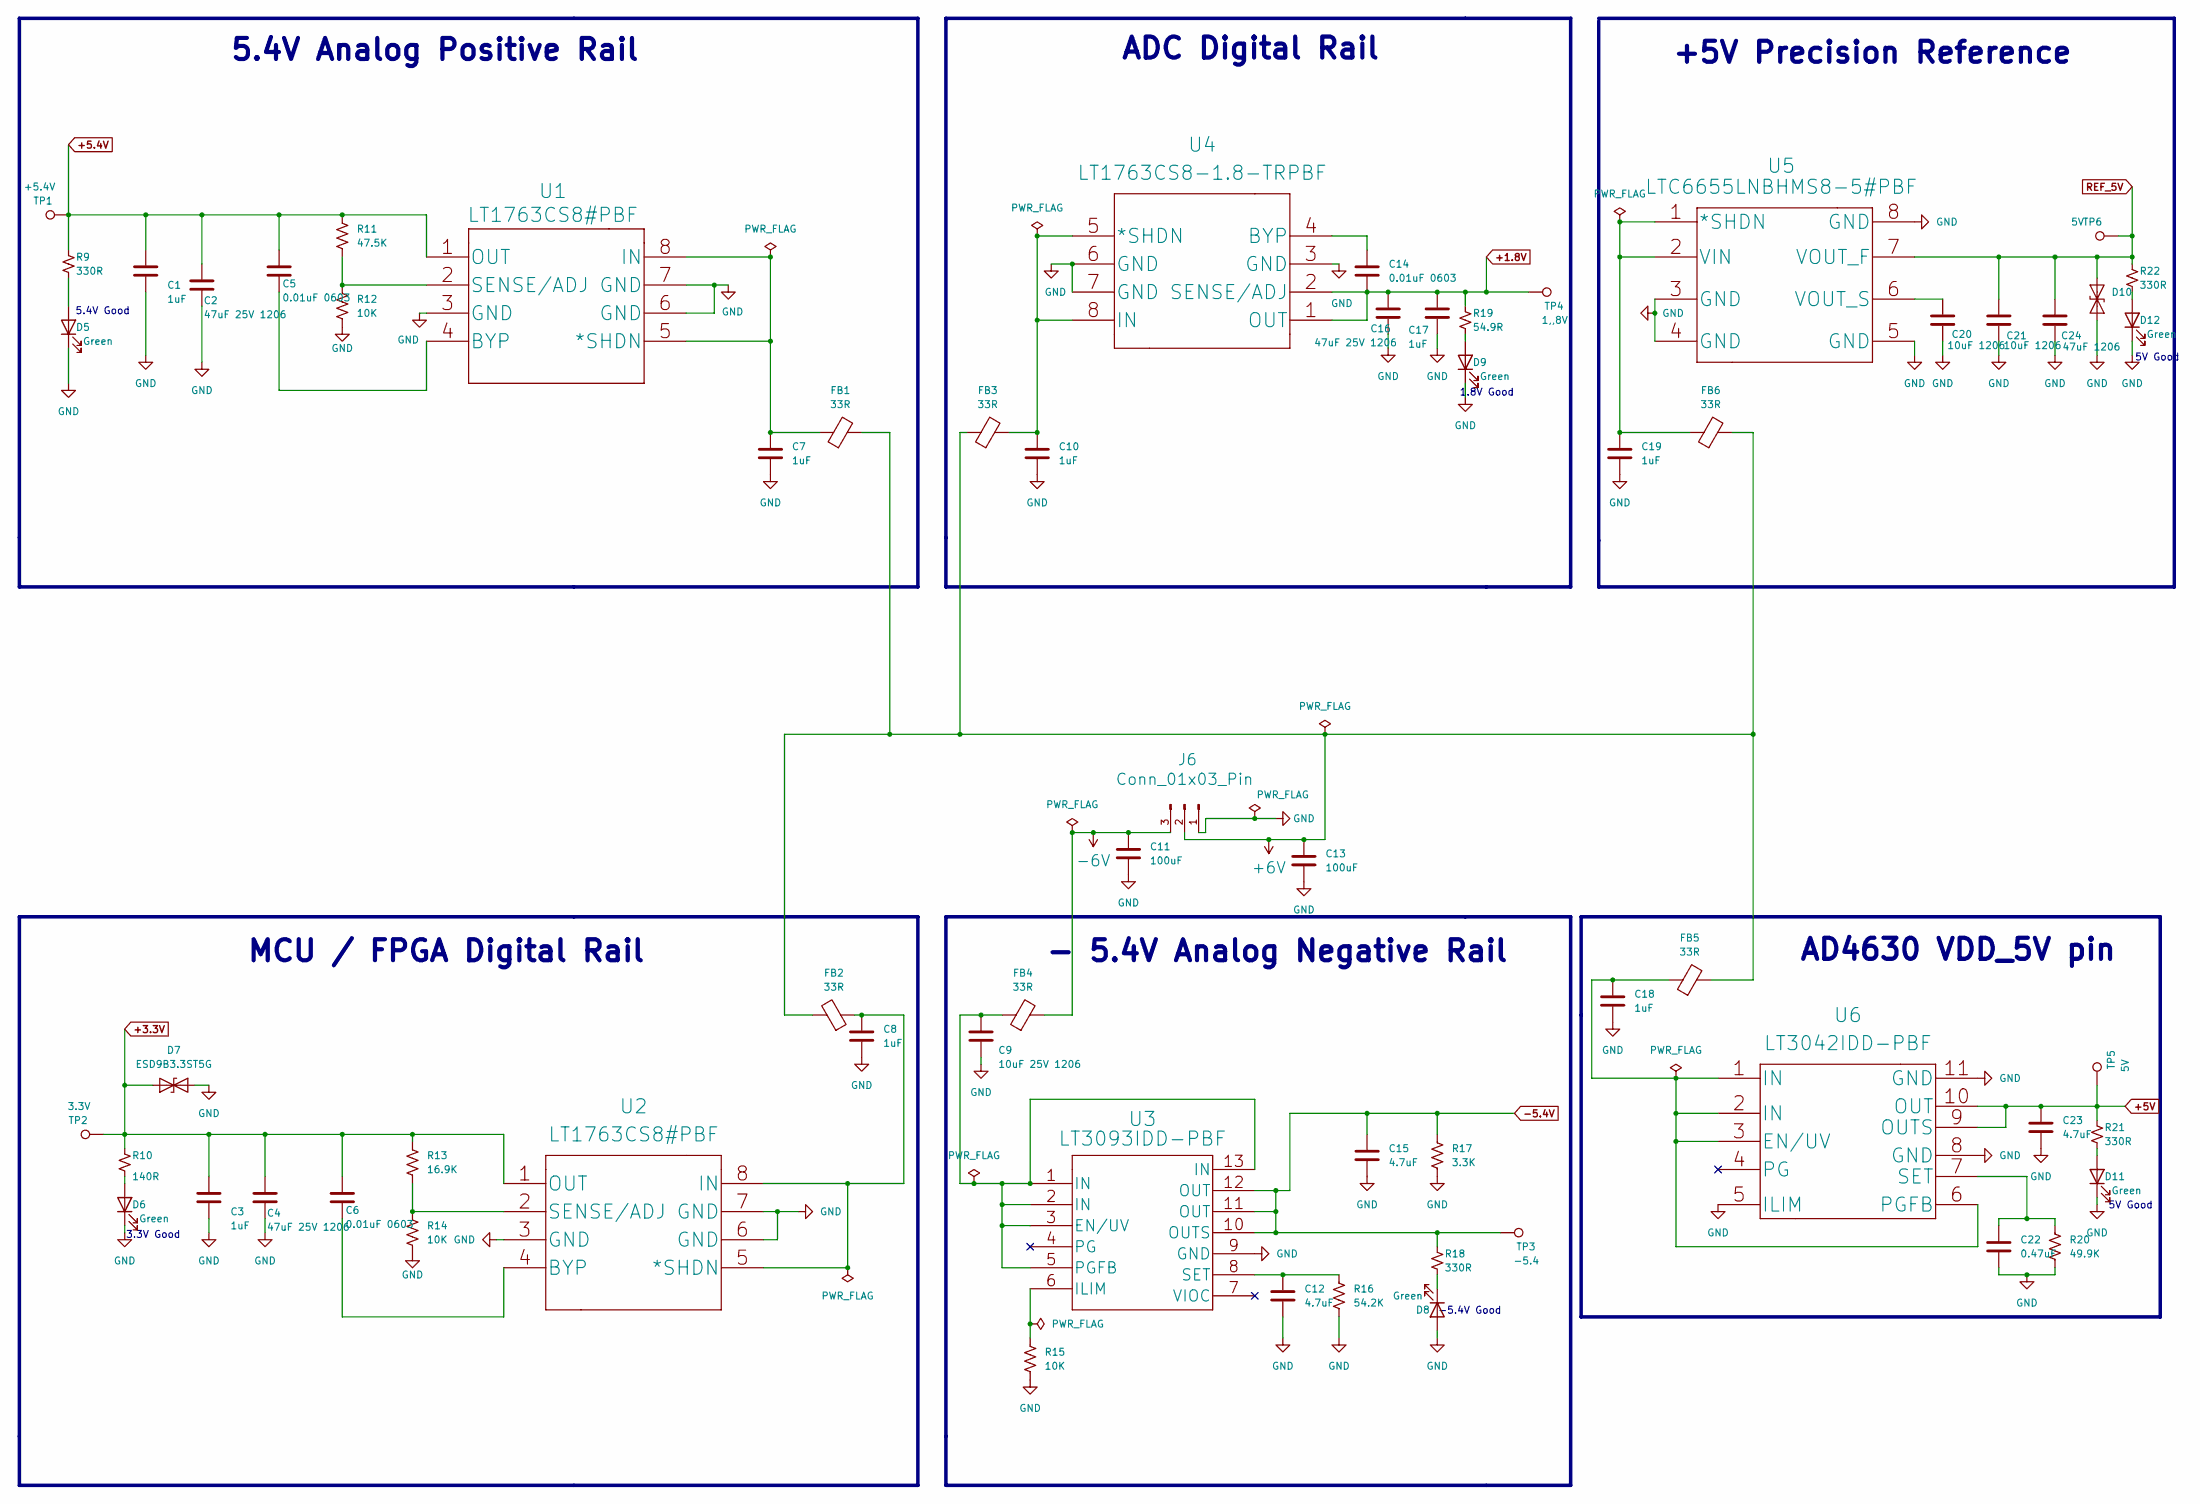
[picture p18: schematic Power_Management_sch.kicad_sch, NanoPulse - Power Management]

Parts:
C1, C3, C7, C8, C10, C17, C18, C19: 1uF; C_0603_1608Metric; Mfg part # CL10B105KP8NNNC; Digikey 1276-1946-1-ND
C2, C4, C16: 47uF 25V 1206; C_1206_3216Metric; Mfg part # GMC31X5R476M25NT; Digikey 4713-GMC31X5R476M25NTCT-ND
C5, C6, C14: 0.01uF 0603; C_0603_1608Metric; Mfg part # C0603C103J5REC7411; Digikey 399-17568-1-ND
C9: 10uF 25V 1206; C_1206_3216Metric; Mfg part # CL31A106MAHNNNE; Digikey 1276-1181-1-ND
C11, C13: 100uF; CP_EIA-3528-21_Kemet-B; Mfg part # TPSB107K006R0400; Digikey 478-4976-1-ND - Cut Tape
C12, C15, C23: 4.7uF; C_0805_2012Metric; Mfg part # CL21A475KAQNNNE; Digikey 1276-1244-1-ND
C20, C21: 10uF 1206; C_1206_3216Metric; Mfg part # CL31A106MAHNNNE; Digikey 1276-1181-1-ND
C22: 0.47uF; C_0805_2012Metric; Mfg part # CL21B474KAFNNNG; Digikey 1276-6480-1-ND
C24: 47uF 1206; C_1206_3216Metric; Mfg part # GMC31X5R476M25NT; Digikey 4713-GMC31X5R476M25NTCT-ND
D5, D6, D8, D9, D11, D12: Green; LED_0603_1608Metric; Mfg part # LTST-C191KGKT; Digikey 160-1446-1-ND
D7: ESD9B3.3ST5G; D_SOD-923; Mfg part # ESD9B3.3ST5G; Digikey ESD9B3.3ST5GOSCT-ND
D10: ESD9B5.0ST5G; D_SOD-923; Mfg part # ESD9B5.0ST5G; Digikey ESD9B5.0ST5GOSCT-ND - Cut Tape
FB1, FB2, FB3, FB4, FB5, FB6: 33R; L_0603_1608Metric_Pad1.05x0.95mm_HandSolder; Mfg part # BLM18PG330SN1D; Digikey 490-5220-1-ND
J6: Conn_01x03_Pin; PhoenixContact_MC_1,5_3-G-3.5_1x03_P3.50mm_Horizontal; Mfg part # PRPC003SAAN-RC; Digikey S1011EC-03-ND
R9, R18, R21, R22: 330R; R_0603_1608Metric; Mfg part # CRGP0603F330R; Digikey A130410CT-ND
R10: 140R; R_0603_1608Metric; Mfg part # ERJ-3EKF1400V; Digikey P140HCT-ND
R11: 47.5K; R_0603_1608Metric; Mfg part # RC0603FR-071KL; Digikey 311-47.5KHRCT-ND
R12, R14, R15: 10K; R_0603_1608Metric; Mfg part # RC0603FR-0710KL; Digikey 311-10.0KHRCT-ND
R13: 16.9K; R_0603_1608Metric; Mfg part # RMCF0603FT16K9; Digikey RMCF0603FT16K9CT-ND
R16: 54.2K; R_0603_1608Metric; Mfg part # RN73H1JTTD5422B25; Digikey 2019-RN73H1JTTD5422B25CT-ND
R17: 3.3K; R_0603_1608Metric; Mfg part # RC0603FR-073K3L; Digikey 311-3.30KHRCT-ND
R19: 54.9R; R_0603_1608Metric; Mfg part # RC0603FR-0754R9L; Digikey 311-54.9HRCT-ND
R20: 49.9K; R_0603_1608Metric; Mfg part # RC0603FR-0756KL; Digikey 311-56KHRCT-ND
TP1: +5.4V; TestPoint_Pad_1.0x1.0mm
TP2: 3.3V; TestPoint_Pad_1.0x1.0mm
TP3: -5.4; TestPoint_Pad_1.0x1.0mm
TP4: 1,,8V; TestPoint_Pad_1.0x1.0mm
TP5, TP6: 5V; TestPoint_Pad_1.0x1.0mm
U1, U2: LT1763CS8#PBF; SO-8_S_LIT-L; Mfg part # LT1763CS8#PBF; Digikey 505-LT1763CS8#PBF-ND
U3: LT3093IDD-PBF; 05-08-1725_ADI; Mfg part # LT3093IDD#PBF; Digikey 505-LT3093IDD#PBF-ND
U4: LT1763CS8-1.8-TRPBF; SO-8_S_LIT; Mfg part # LT1763CS8-1.8#TRPBF; Digikey 505-LT1763CS8-1.8#TRPBFCT-ND
U5: LTC6655LNBHMS8-5#PBF; MSOP-8_MS_LIT-L; Mfg part # LTC6655LNBHMS8-5#PBF; Digikey 505-LTC6655LNBHMS8-5#PBF-ND
U6: LT3042IDD-PBF; DFN-10_DD_LIT; Mfg part # LT3042IDD#TRPBF; Digikey LT3042IDD#TRPBFCT-ND

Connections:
+1.8V: C14.2, C16.1, C17.1, R19.1, TP4.1, U4.1 (OUT), U4.2 (SENSE/ADJ); also elsewhere on the board
+3.3V: C3.1, C4.1, C6.1, D7.1 (A1), R10.1, R13.1, TP2.1, U2.1 (OUT); also elsewhere on the board
+5.4V: C1.1, C2.1, C5.1, R9.1, R11.1, TP1.1, U1.1 (OUT); also elsewhere on the board
+5V: C23.2, R21.1, TP5.1, U6.9 (OUTS), U6.10 (OUT); also elsewhere on the board
+6V: C13.1, FB1.2, FB2.2, FB3.1, FB5.2, FB6.2, J6.2
-5.4V: C15.1, R17.1, R18.1, TP3.1, U3.10 (OUTS), U3.11 (OUT), U3.12 (OUT); also elsewhere on the board
-6V: C11.1, FB4.2, J6.3
GND: C1.2, C2.2, C3.2, C4.2, C7.2, C8.2, C9.2, C10.2, C11.2, C12.2, C13.2, C15.2, C16.2, C17.2, C18.2, C19.2, C20.2, C21.2, C22.1, C23.1, C24.2, D5.1 (K), D6.1 (K), D7.2 (A2), D8.2 (A), D9.1 (K), D10.2 (A2), D11.1 (K), D12.1 (K), J6.1, R12.2, R14.2, R15.2, R16.2, R17.2, R20.1, U1.3 (GND), U1.6 (GND), U1.7 (GND), U2.3 (GND), U2.6 (GND), U2.7 (GND), U3.9 (GND), U4.3 (GND), U4.6 (GND), U4.7 (GND), U5.3 (GND), U5.4 (GND), U5.5 (GND), U5.8 (GND), U6.5 (ILIM), U6.8 (GND), U6.11 (GND); also elsewhere on the board
unnamed: D5.2 (A), R9.2
unnamed: D6.2 (A), R10.2
unnamed: D8.1 (K), R18.2
unnamed: D9.2 (A), R19.2
unnamed: D11.2 (A), R21.2
unnamed: D12.2 (A), R22.2
unnamed: C7.1, FB1.1, U1.5 (*SHDN), U1.8 (IN)
unnamed: C5.2, U1.4 (BYP)
unnamed: R11.2, R12.1, U1.2 (SENSE/ADJ)
unnamed: C8.1, FB2.1, U2.5 (*SHDN), U2.8 (IN)
unnamed: C6.2, U2.4 (BYP)
unnamed: R13.2, R14.1, U2.2 (SENSE/ADJ)
unnamed: C9.1, FB4.1, U3.1 (IN), U3.2 (IN), U3.3 (EN/UV), U3.5 (PGFB), U3.13 (IN)
unnamed: R15.1, U3.6 (ILIM)
unnamed: C12.1, R16.1, U3.8 (SET)
unnamed: C10.1, FB3.2, U4.5 (*SHDN), U4.8 (IN)
unnamed: C14.1, U4.4 (BYP)
unnamed: C19.1, FB6.1, U5.1 (*SHDN), U5.2 (VIN)
unnamed: C20.1, U5.6 (VOUT_S)
unnamed: C18.1, FB5.1, U6.1 (IN), U6.2 (IN), U6.3 (EN/UV), U6.6 (PGFB)
unnamed: C22.2, R20.2, U6.7 (SET)
REF_5V: C21.1, C24.1, D10.1 (A1), R22.1, TP6.1, U5.7 (VOUT_F); also elsewhere on the board

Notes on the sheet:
-5.4V Good
ADC Digital Rail
MCU / FPGA Digital Rail
5.4V Analog Positive Rail
1.8V Good
- 5.4V Analog Negative Rail
AD4630 VDD_5V pin
5V Good
5.4V Good
3.3V Good
+5V Precision Reference

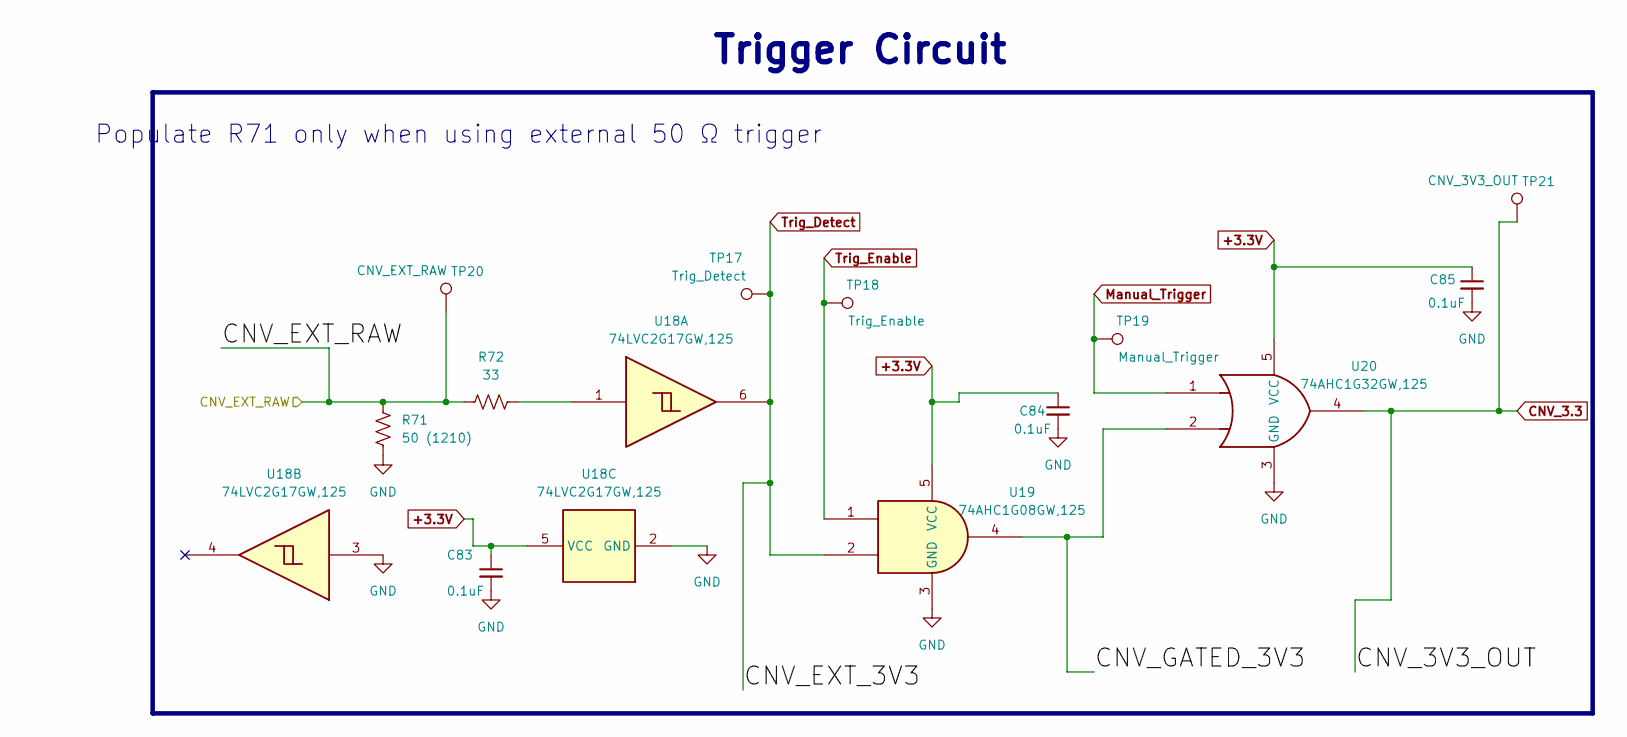
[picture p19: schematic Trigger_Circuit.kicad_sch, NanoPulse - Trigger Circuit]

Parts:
C83, C84, C85: 0.1uF; C_0603_1608Metric; Mfg part # CC0603KRX7R7BB104; Digikey 311-1088-1-ND
R71: 50 (1210); R_1210_3225Metric_Pad1.30x2.65mm_HandSolder; Mfg part # RCP1206W50R0JTP; Digikey 541-RCP1206W50R0JTPCT-ND
R72: 33; R_0603_1608Metric; Mfg part # RC0603FR-072KL; Digikey 311-33GRCT-ND
TP17: Trig_Detect; TestPoint_Pad_1.0x1.0mm
TP18: Trig_Enable; TestPoint_Pad_1.0x1.0mm
TP19: Manual_Trigger; TestPoint_Pad_1.0x1.0mm
TP20: CNV_EXT_RAW; TestPoint_Pad_1.0x1.0mm
TP21: CNV_3V3_OUT; TestPoint_Pad_1.0x1.0mm
U18: 74LVC2G17GW,125; SOT-363_SC-70-6; Mfg part # 74LVC2G17GW,125; Digikey 1727-4218-1-ND
U19: 74AHC1G08GW,125; SOT-353_SC-70-5; Mfg part # 74AHC1G08GW,125; Digikey 1727-3148-1-ND
U20: 74AHC1G32GW,125; SOT-353_SC-70-5; Mfg part # 74AHC1G32GW,125; Digikey 1727-3150-1-ND

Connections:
+3.3V: C83.1, C84.1, C85.1, U18.5 (VCC), U19.5 (VCC), U20.5 (VCC); also elsewhere on the board
/Trigger Circuit/CNV_EXT_RAW: R71.1, R72.2, TP20.1; also elsewhere on the board
/Trigger Circuit/CNV_GATED_3V3: U19.4, U20.2
CNV_3.3: TP21.1, U20.4; also elsewhere on the board
GND: C83.2, C84.2, C85.2, R71.2, U18.2 (GND), U18.3, U19.3 (GND), U20.3 (GND); also elsewhere on the board
Manual_Trigger: TP19.1, U20.1; also elsewhere on the board
unnamed: R72.1, U18.1
Trig_Detect: TP17.1, U18.6, U19.2; also elsewhere on the board
Trig_Enable: TP18.1, U19.1; also elsewhere on the board

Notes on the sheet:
Populate R71 only when using external 50 Ω trigger
Trigger Circuit

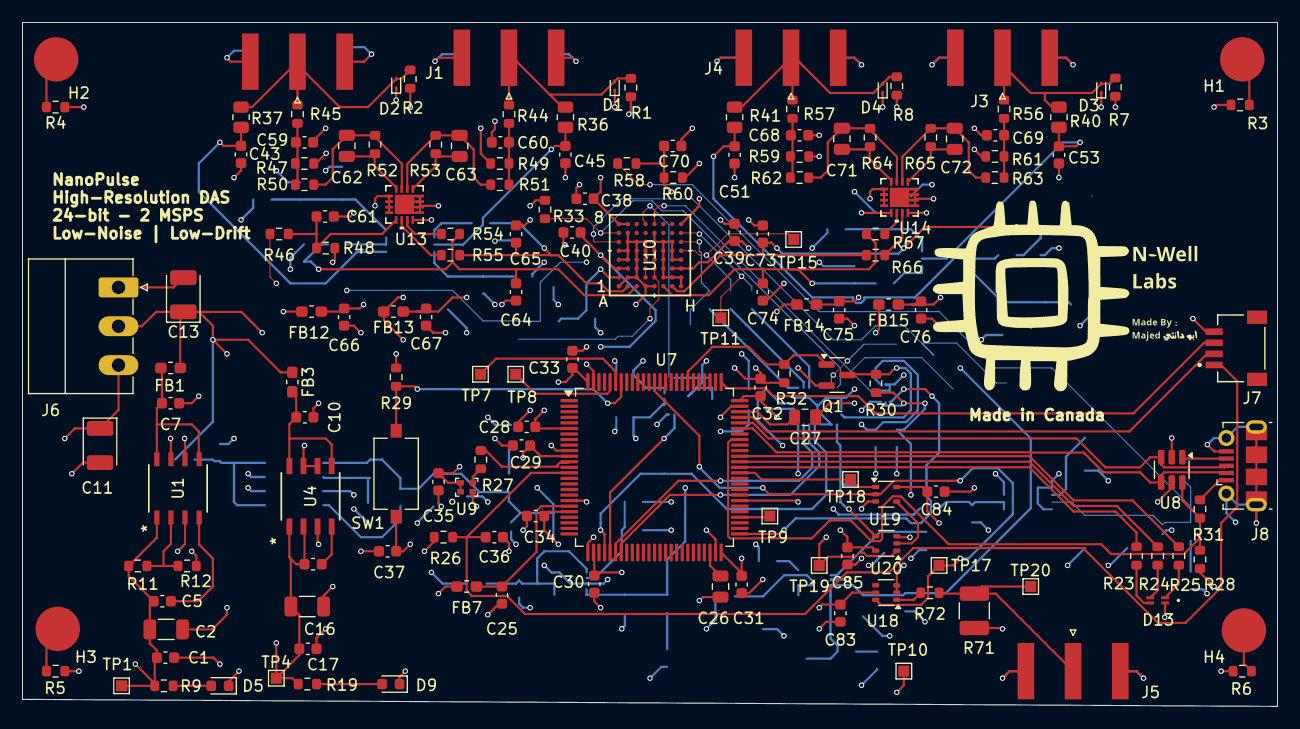
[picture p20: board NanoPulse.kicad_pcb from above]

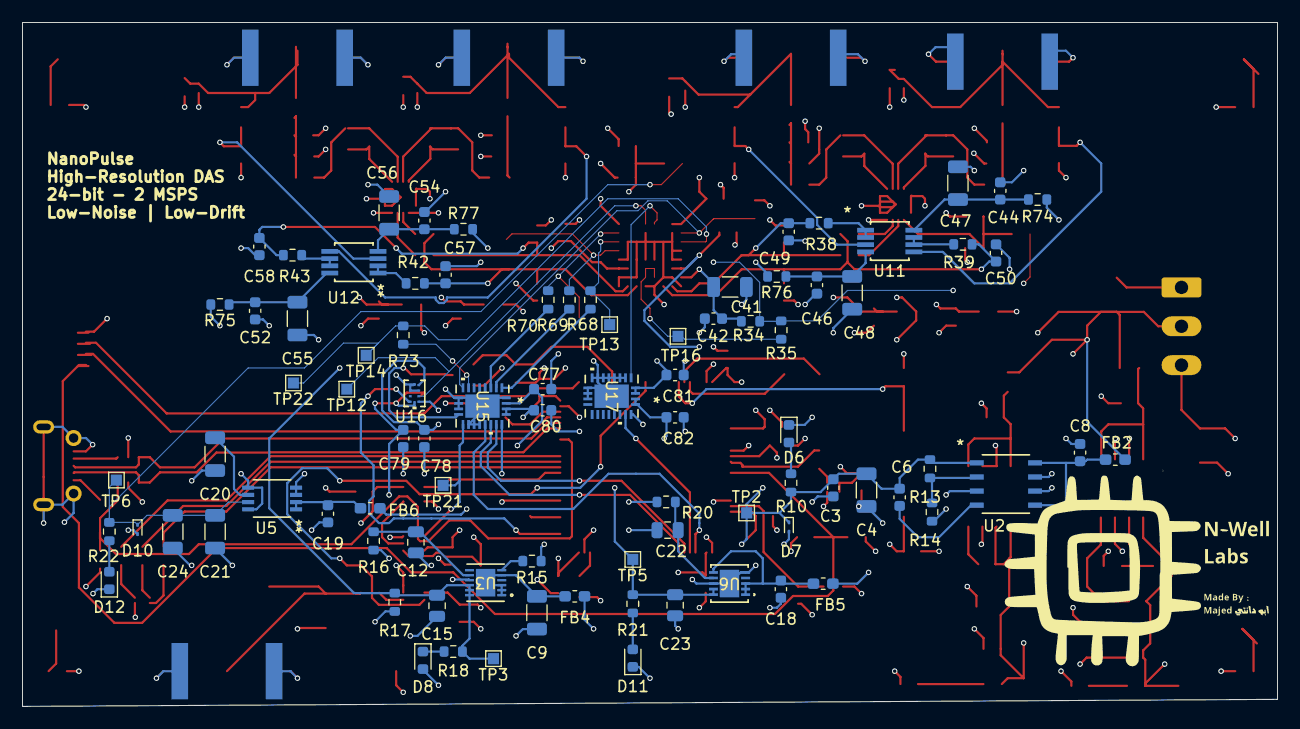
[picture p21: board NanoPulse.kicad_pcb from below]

Board: 4 copper layers, 113.0 x 61.6 mm, 244 parts (88 on the bottom side), 126 nets.

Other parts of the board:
Logo1#2: Majed's Logo; Logo_Majed_small

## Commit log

2025-07-12 Just completed the power management system
    [ADC.kicad_sch, ADC_Driver_Stage-Final-Buffer.kicad_sch, MCU-FPGA.kicad_sch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]
2025-07-15 edited Power management schematic
    [Power_Management_sch.kicad_sch]
2025-08-10 All done, Gerberd out :)
    [ADC.kicad_sch, ADC_Driver_Stage-Final-Buffer.kicad_sch, Analog front-end_ADC-Driver.kicad_sch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]
2025-08-10 Extra signal conditioning
    [ADC_Driver_Stage-Final-Buffer.kicad_sch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]
